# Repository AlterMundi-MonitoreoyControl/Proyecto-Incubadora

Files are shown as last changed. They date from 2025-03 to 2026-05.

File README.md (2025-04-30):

# LibreIncu 

Is an innovative project aimed at enhancing the efficiency and productivity of poultry incubators in family farming. Developed by Asociación Civil AlterMundi and CTO, this system integrates advanced monitoring and control technologies to optimize temperature and humidity levels, reducing manual labor and increasing hatch rates. Utilizing free hardware and software, the project promotes sustainable agricultural practices and empowers local communities with technical skills. Join us in revolutionizing family farming with technology!

(https://editor.plantuml.com/uml/ZLF1JW8n4BttAoPSXCCUG43mO20a6WvUnCIB2HdQMMtijfks2_ht3Wj85z2OR3RPwNipxxtEJa947wl2YF2XROaU2r2KOsNYCtt6gT5ljY0RGVABl13MAOBMtCfgXSfvXF5mq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)

Each incubator broadcasts a Wi-Fi network with a name that starts with “incu-” followed by a number. A user who wants to control their incubator can connect to this Wi-Fi network and change the incubator paramteres using the android app. Additionally, each incubator also connects to an external Wi-Fi network to send data over the internet to a remote Grafana server.

## LibreIncu en los medios
Aquí encontrarás enlaces a 

### Notas y artículos periodísticos 
Tiempo Argentino.Tiempo Rural.

Crean “LibreIncu”, una incubadora para familias productoras que funciona con software libre
https://bit.ly/LibreIncu

Pagina 12.

Problemas en la salud, maltrato animal y pérdida de soberanía. ¿Qué hacer con la industria avícola?
https://www.pagina12.com.ar/798691-que-hacer-con-la-industria-avicola

Multimedio Comechingones: 

INCUBADORAS LIBRES Y LA SOBERANÍA ALIMENTARIA Y TECNOLÓGICA.
https://www.youtube.com/watch?v=XAIEJV1IsmM

Radio Pueblo 103.3

Somos Tierra (programa) 07/03
“LibreIncu”, una incubadora para familias productoras que funciona con software libre.
https://www.facebook.com/100064102022746/posts/pfbid0N8CtLHdo2AVj12pVsAtcoeShCmByB2GCyXqmLqw75aoo8GYHFhkMTCCCVQQF8PBvl/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

CDM Noticias: 

👉🏽En una entrevista radial con CDM Noticias, Fabricio Puzio, integrante de la organización rural CTO y uno de los impulsores del proyecto, brindó detalles del proyecto
https://cdmnoticias.com.ar/2025/03/11/libreincu-una-incubadora-de-pollos-con-software-libre-para-la-agricultura-familiar-en-cordoba/

### Videos

En este video encontrarán las voces de las comunidades que recibieron la incubadora en 1ra persona:
Youtube: https://youtu.be/KnWVigydmrw
Drive (para descarga archivo):
https://drive.google.com/file/d/1XJGJvUBiZXpjTJCaMYPYS3Le8TjS4YHT/view?usp=drive_link

Este video resume la actividad de febrero de 2025, dónde se realizó una capacitación técnica sobre el uso de la incubadora y su entrega a las comunidades:
Youtube: https://youtu.be/x1D_cCt7HYg
Drive (archivo):
https://drive.google.com/file/d/1NNPJ5_CfbWtDd18YyunTMB_yW_l8wr9t/view?usp=drive_link

En este video, encontrarán las voces del Equipo de Altermundi, reflexionando sobre el proceso de desarrollo.
Youtube: https://youtu.be/SZky4Ak8hUw
Drive (archivo):
https://drive.google.com/file/d/1BhJ7BwKUeTCceVNzBBIgxEsvleegejvH/view?usp=drive_link

En este video encontrarán testimonios sobre lo que implica el proyecto de desarrollo para las organizaciones involucradas.
Youtube: https://youtu.be/OzdKqgwdBYY

En este video encontrarán una presentación técnica Incubadora, con sus componentes:
https://www.youtube.com/watch?v=WrC1Y-ACtMo
Corte cuadrado 1:
https://drive.google.com/file/d/1Y_UQ-bno3-HFeVKtA_xg6CsesUtA-4hE/view?usp=drive_link
Corte cuadrado 2:
https://drive.google.com/file/d/13rHx7xk9e1rThg5PIM3QHikm3YS5sNPg/view?usp=drive_link

En este video encontrarán testimonios sobre la 1er Capacitación realizada con las comunidades sobre manejo productivo de huevos fértiles e incubadora.
https://youtu.be/IfGGvOIJ1b8
https://drive.google.com/file/d/1ajWQofPJQxNfXo5LtOdFrOzkCoTbWGiC/view?usp=sharing

## made with :heart: by:

<p align="center" width="100%">
    
</p>

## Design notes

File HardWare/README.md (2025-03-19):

# Project-Incubadora Hardware



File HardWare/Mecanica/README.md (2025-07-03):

# LibreIncu: 3D Model Overview

This repository includes a 3D printable part of the LibreIncu incubator project.

## 🔍 STL Preview

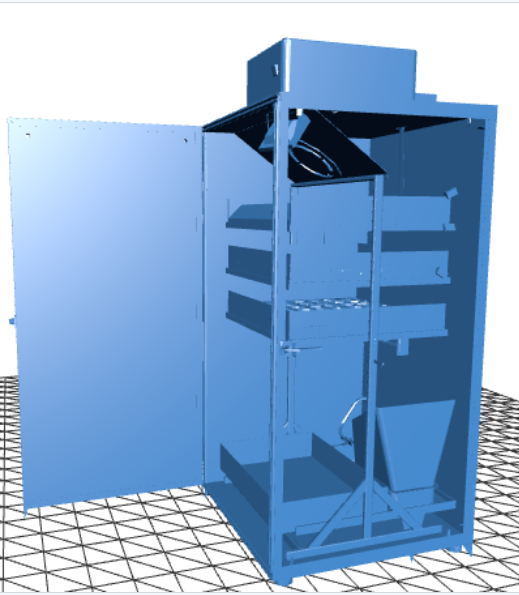
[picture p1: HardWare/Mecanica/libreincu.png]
LibreIncu 3D Preview


## 📦 Download STL

You can download the 3D model file here:

🔗 [`LibreIncu-STL.simple.stl`](./LibreIncu-STL.simple.stl)

## 🛠️ About the Model

- Format: STL (for 3D printing)
- Material suggestion: PLA or PETG
- Print orientation: Flat on base
- License: [Your License Here]

## 📁 File Location

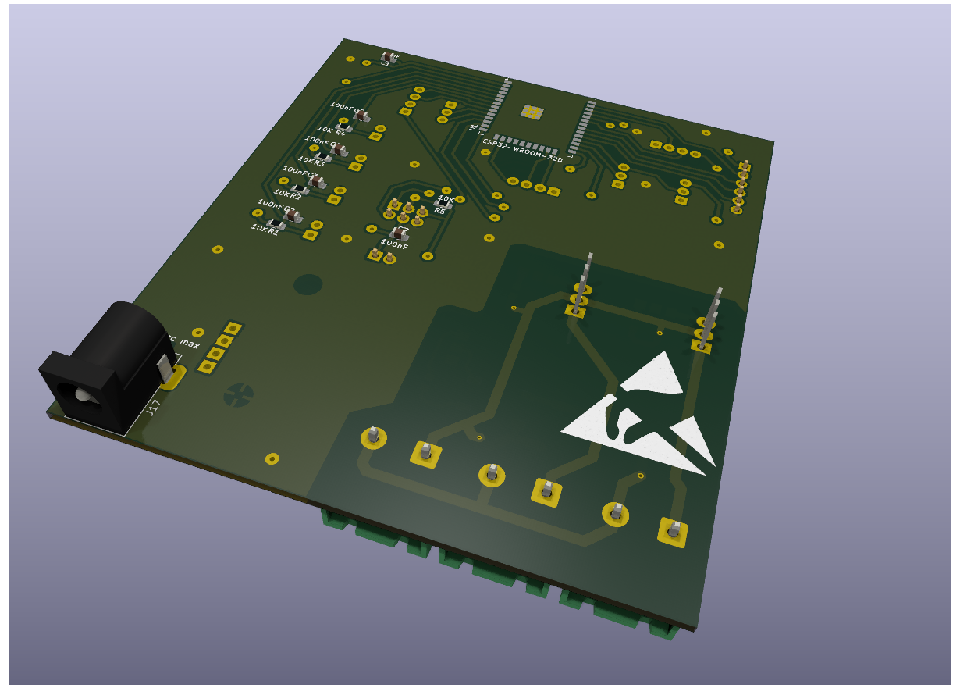
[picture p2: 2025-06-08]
HardWare/Electro/Olivia_control/v0.2/v0.2-vista2.png

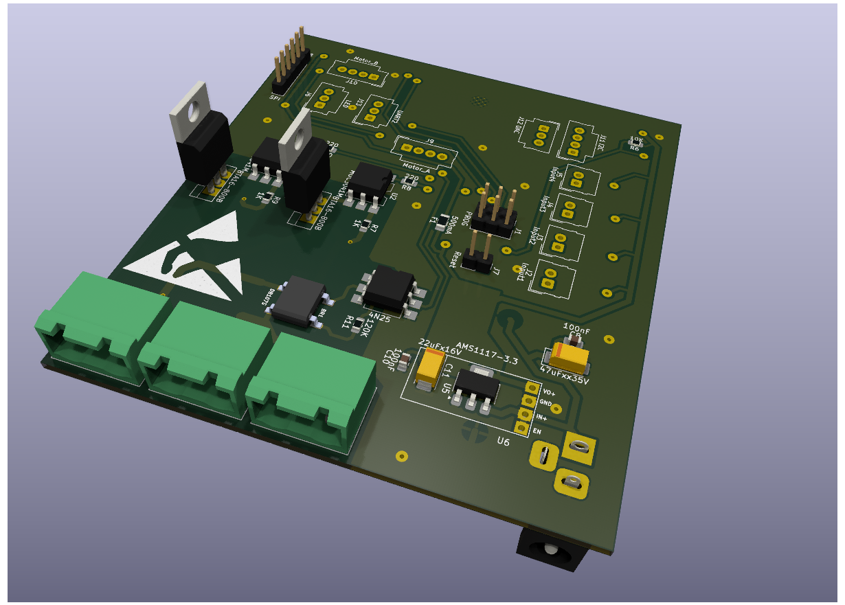
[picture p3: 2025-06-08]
HardWare/Electro/Olivia_control/v0.2/v0.2-vista1.png

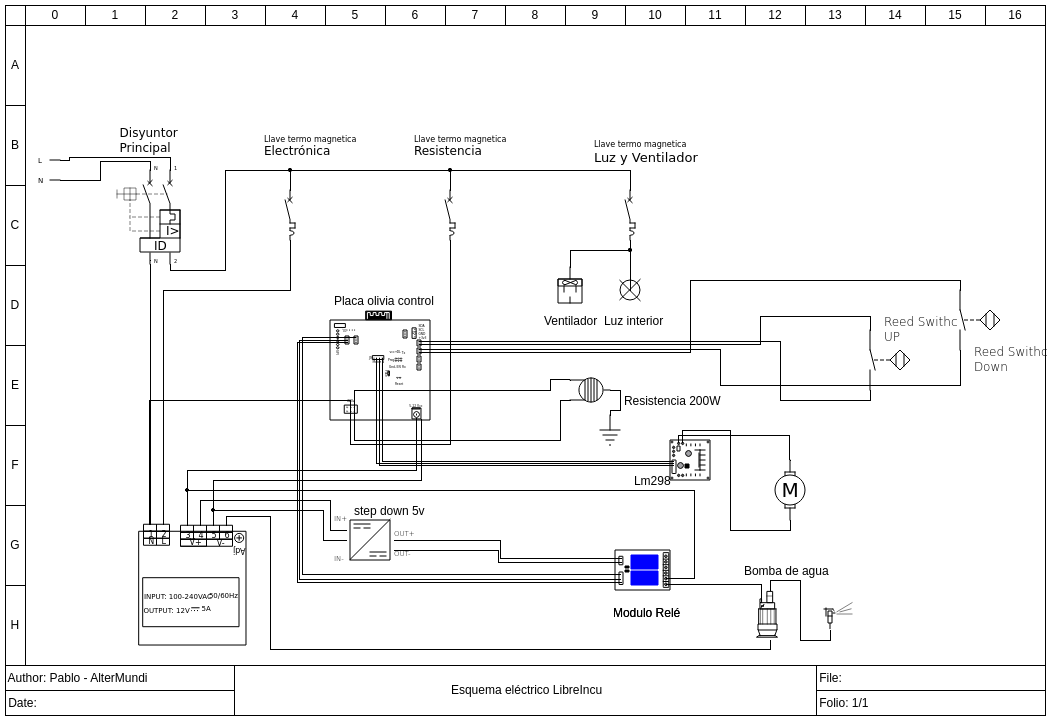
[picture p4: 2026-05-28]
HardWare/Electro/1_esquema_eléctrico_libreincu.png

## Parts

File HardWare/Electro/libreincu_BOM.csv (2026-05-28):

Subsistema | Componente | Cantidad | Especificación | Estado | Referencia / Link | Notas | Responsable
Alimentación | Fuente switching | 1 | 12V 5A con ventilación FSI-1205-Classic | definido | https://www.mercadolibre.com.ar/fuente-switching-12v-5a-proteccion-ventilada-fsi-1205-clasic/p/MLA308325457
Alimentación | Módulo step down | 1 | LM2596 regulable 1,3V–35V 3A | definido | https://articulo.mercadolibre.com.ar/MLA-1249465246-modulo-regulador-fuente-step-down-lm2596s-130v-35v-pack-x10-_JM |  | Fabri
Alimentación | Gabinete plástico | 1 | 25x25 o 20x20 cm IP65 | definido | https://www.mercadolibre.com.ar/caja-estanca-plastica-210x310x110-mm-blanca-ip65-color-blanco/p/MLA268881998
Alimentación | Disyuntor diferencial | 1 | Bipolar 2x 25A | definido | https://articulo.mercadolibre.com.ar/MLA-1548430354-interruptor-diferencial-disyuntor-bipolar-2x-25a-baw-_JM
Control electrónico | PCB (placa de control Olivia) | 1 | Diseño propio LibreIncu | repositorio | https://github.com/AlterMundi-MonitoreoyControl/Proyecto-Incubadora | Ver diseño en repositorio GitHub
Control electrónico | Sensor BME280 | 1 | Temperatura / humedad / presión I²C | verificar |  | Hay de impresora — averiguar si sirven. 3 dudosos | Pablo
Control electrónico | Sensores Reed (finales de carrera) | 2 | Sensor magnético para puerta/ventana | definido | https://articulo.mercadolibre.com.ar/MLA-878544727-sensor-magnetico-para-alarma-puerta-y-ventana-seguridad-_JM | Pack x6
Control electrónico | Resistencia calefactora | 1 | 200W (tipo panchera industrial) | definido | https://myaccount.mercadolibre.com.ar/my_purchases/200000938165593 |  | Fabri
Electricidad y protecciones | Interruptor termomagnético | 3 | Automático miniatura DIN límite 782105 | definido | https://articulo.mercadolibre.com.ar/MLA-908151554-interruptor-automatico-miniatura-para-riel-din-sica-limit-782105
Electricidad y protecciones | Llave palanca (interruptor) | 2 | 250V on-off 2 contactos | definido | https://articulo.mercadolibre.com.ar/MLA-908151554-llave-palanca-10a-250v-on-off-2-contactos-interruptora-_JM
Electricidad y protecciones | Cable taller tripolar | 2 | 3x2 5 mm² | 5 mm² | definido | https://articulo.mercadolibre.com.ar/MLA-912939764-cable-taller-tripolar-3-x-25-mm-x-mts-_JM | Metros según diseño
Electricidad y protecciones | Cable para sensores | 3 | Multiconductor fino | definido |  | Hay de impresora | Pablo
Electricidad y protecciones | Prensacables | 5 |  | definido
Electricidad y protecciones | Enchufe | 1 | Ficha macho recto salida trasera 10A | definido | https://articulo.mercadolibre.com.ar/MLA-1404782284-pack-x10-ficha-macho-richi-salida-trasera-3-patas_JM
Electricidad y protecciones | Luz LED | 1 | Proyector reflector LED 10W luz fría | definido | https://articulo.mercadolibre.com.ar/MLA-1400729612-proyector-reflector-led-10w-luz-fria-blanco_JM
Electricidad y protecciones | Resistencia horno (grill) | 1 | 36A 53cm — horno eléctrico grill velas | definido | https://articulo.mercadolibre.com.ar/MLA-654604457-resistencia-horno-electrico-grill-velas_JM
Electricidad y protecciones | Cable bipolar 0 | 5mm |  | 24AWG rojo-negro LED x10m | definido | https://articulo.mercadolibre.com.ar/MLA-877971472-cable-bipolar-de-05mm-24-awg-rojo-y-negro-tira-led-x10m-_JM
Humidificación y mecánica | Bomba de agua | 1 | Singflo/SEAFLO 12VCC 4,3 LPM 35 PSI — diafragma con presostato integrado. 3,5A. Salida 3/8". | definido | https://www.mercadolibre.com.ar/bomba-de-agua-43-lpm-12-v-motorhome-casa-rodante-adrogue/up/MLAU276483609
Humidificación y mecánica | Motorreductor volteo | 1 | Ignis MR08B-012004 — 12 VCC 4W cupla máx. 88 kgf·cm eje 8mm 17 rpm | definido | https://ignismotor.com/STD-ES/PDF/MR08B-012004.pdf | Volteo automático de bandejas
Humidificación y mecánica | Ventilador turbina con rodamiento | 1 | 220 VAC 50Hz — 120x120mm axial con rulemán. Modelo tipo CT4 A7 o similar. | definido | https://articulo.mercadolibre.com.ar/MLA-620399442-turbina-cooler-fan-extractor-220v-ruleman-4-pulgadas-120x38m-_JM | Circulación forzada de aire interior. VT-POWER CT4 o equivalente con rodamiento (no manguito)
Humidificación y mecánica | Caja estanca 20x25 | 1 | 210x310x110mm IP65 | definido | https://www.mercadolibre.com.ar/caja-estanca-plastica-210x310x110-mm-blanca-ip65-color-blanco/p/MLA268881998

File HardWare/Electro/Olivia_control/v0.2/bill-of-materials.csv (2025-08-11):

Reference | Value | Footprint | Qty
BR1 | DB107S | lib:DIOB_DB107S | 1
C1 | 10uF | Capacitor_SMD:C_0805_2012Metric_Pad1.18x1.45mm_HandSolder | 1
C2,C3,C4,C5,C7,C8,C10 | 100nF | Capacitor_SMD:C_0805_2012Metric_Pad1.18x1.45mm_HandSolder | 7
C9 | 47uFxx35V | Capacitor_Tantalum_SMD:CP_EIA-6032-28_Kemet-C_Pad2.25x2.35mm_HandSolder | 1
C11 | 22uFx16V | Capacitor_Tantalum_SMD:CP_EIA-6032-28_Kemet-C_Pad2.25x2.35mm_HandSolder | 1
F1 | 500mA | Fuse:Fuse_1206_3216Metric_Pad1.42x1.75mm_HandSolder | 1
J1 | PROG | Connector_PinHeader_2.54mm:PinHeader_2x03_P2.54mm_Vertical | 1
J2 | Input1 | Connector_Molex:Molex_SL_171971-0002_1x02_P2.54mm_Vertical | 1
J3 | Input2 | Connector_Molex:Molex_SL_171971-0002_1x02_P2.54mm_Vertical | 1
J4 | Input3 | Connector_Molex:Molex_SL_171971-0002_1x02_P2.54mm_Vertical | 1
J5 | Input4 | Connector_Molex:Molex_SL_171971-0002_1x02_P2.54mm_Vertical | 1
J6 | LED | Connector_Molex:Molex_SL_171971-0003_1x03_P2.54mm_Vertical | 1
J7 | Reset | Connector_PinHeader_2.54mm:PinHeader_1x02_P2.54mm_Vertical | 1
J8 | SPI | Connector_PinHeader_2.54mm:PinHeader_1x06_P2.54mm_Vertical | 1
J9 | Motor_A | Connector_Molex:Molex_SL_171971-0004_1x04_P2.54mm_Vertical | 1
J10 | Motor_B | Connector_Molex:Molex_SL_171971-0004_1x04_P2.54mm_Vertical | 1
J11 | I2C | Connector_Molex:Molex_SL_171971-0004_1x04_P2.54mm_Vertical | 1
J12 | DAC | Connector_Molex:Molex_SL_171971-0003_1x03_P2.54mm_Vertical | 1
J13 | UART2 | Connector_Molex:Molex_SL_171971-0003_1x03_P2.54mm_Vertical | 1
J14 | TRIAC OUT_A | Connector_Phoenix_GMSTB:PhoenixContact_GMSTBA_2,5_2-G-7,62_1x02_P7.62mm_Horizontal | 1
J15 | TRIAC OUT_B | Connector_Phoenix_GMSTB:PhoenixContact_GMSTBA_2,5_2-G-7,62_1x02_P7.62mm_Horizontal | 1
J16 | 220V IN | Connector_Phoenix_GMSTB:PhoenixContact_GMSTBA_2,5_2-G-7,62_1x02_P7.62mm_Horizontal | 1
J17 | In12V | Connector_BarrelJack:BarrelJack_Horizontal | 1
Q1,Q2 | BTA16-800B | Package_TO_SOT_THT:TO-220-3_Vertical | 2
R1,R2,R3,R4,R5,R6 | 10K | Resistor_SMD:R_0805_2012Metric_Pad1.20x1.40mm_HandSolder | 6
R7,R9 | 1K | Resistor_SMD:R_0805_2012Metric_Pad1.20x1.40mm_HandSolder | 2
R8,R10 | 220 | Resistor_SMD:R_0805_2012Metric_Pad1.20x1.40mm_HandSolder | 2
R11 | 120K | Resistor_SMD:R_0805_2012Metric_Pad1.20x1.40mm_HandSolder | 1
U1 | ESP32-WROOM-32D | RF_Module:ESP32-WROOM-32D | 1
U2,U3 | MOC3041M | Package_DIP:SMDIP-6_W9.53mm | 2
U4 | 4N25 | Package_DIP:SMDIP-6_W9.53mm | 1
U6 | HW-613 | Connector_PinHeader_2.54mm:PinHeader_1x04_P2.54mm_Vertical | 1

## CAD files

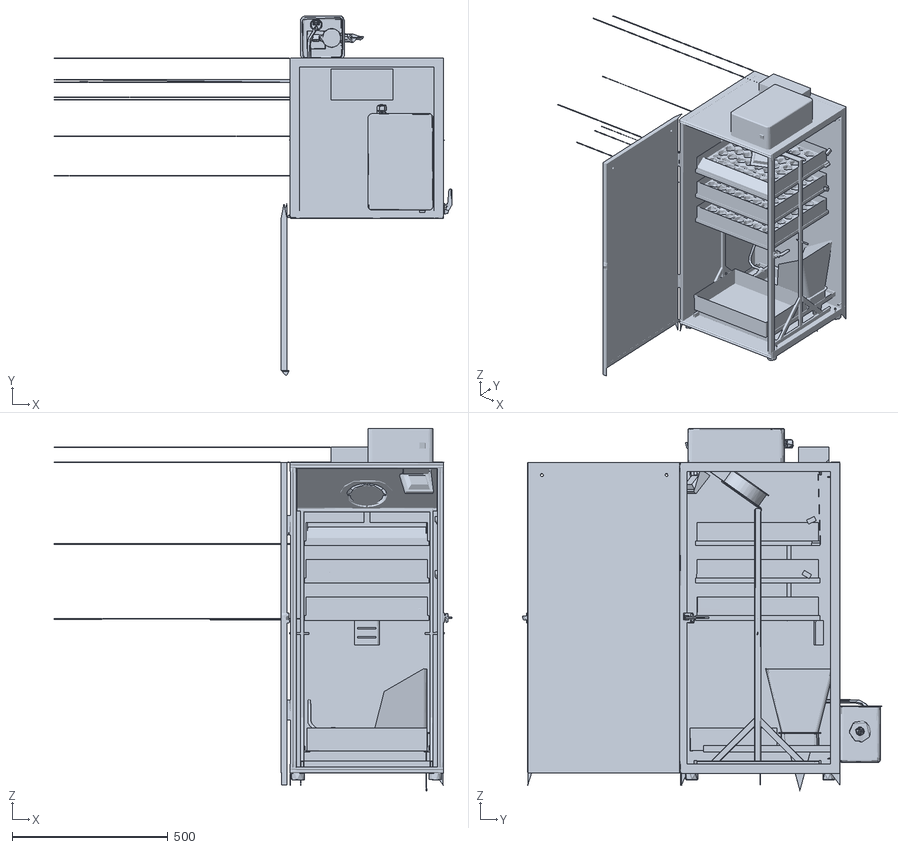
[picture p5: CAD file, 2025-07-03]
HardWare/Mecanica/LibreIncu-STL.simple.stl
1277.2 x 1154.4 x 1162.8

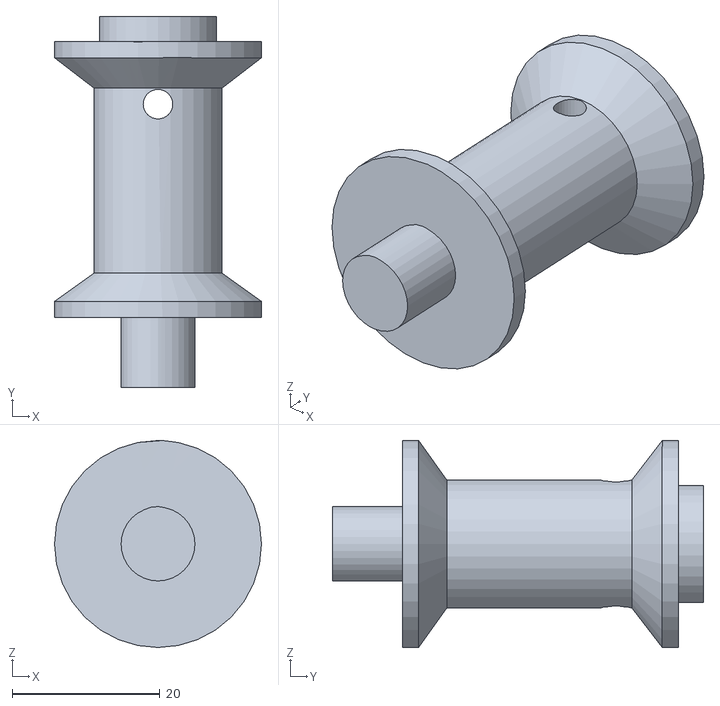
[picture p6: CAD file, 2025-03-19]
HardWare/Mecanica/STLs_rotacion/Polea.stl
28.1 x 50.3 x 28.1

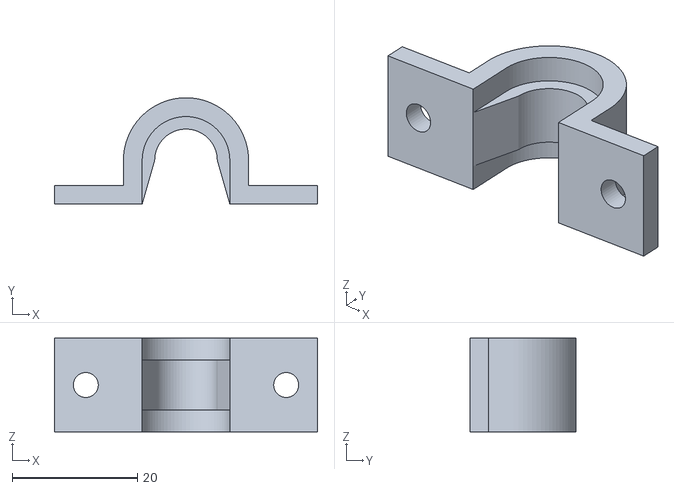
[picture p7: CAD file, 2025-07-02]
HardWare/Mecanica/ALT-INC001-12-03.STL
42.0 x 17.0 x 15.0

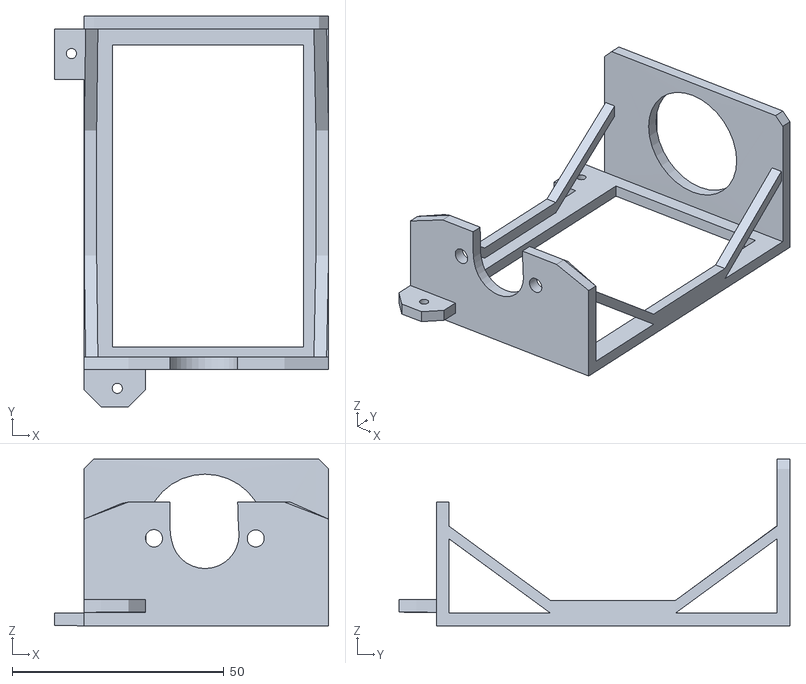
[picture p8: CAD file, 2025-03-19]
HardWare/Mecanica/STLs_rotacion/SoporteMotor.stl
64.8 x 92.4 x 39.4

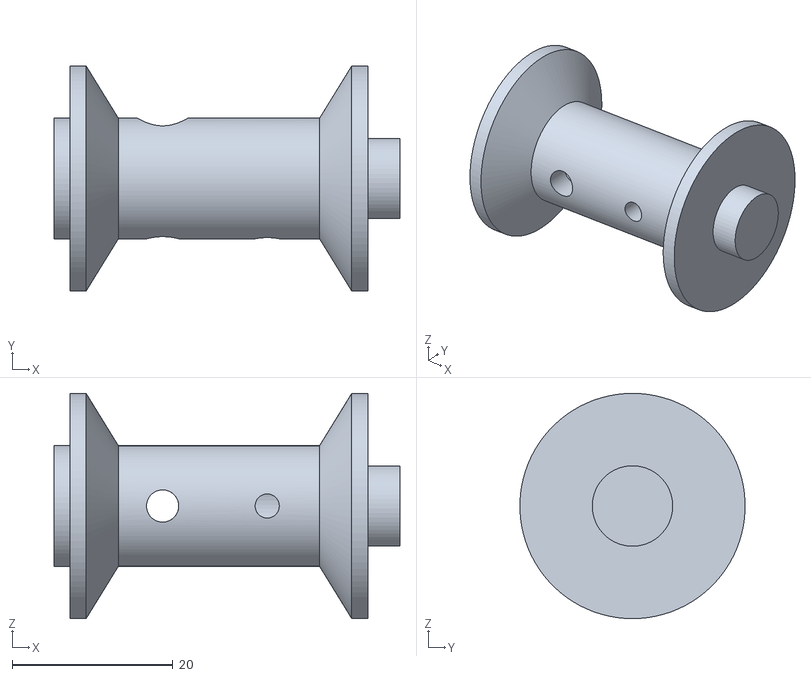
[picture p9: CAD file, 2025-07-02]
HardWare/Mecanica/ALT-INC001-05-01.STL
43.0 x 28.0 x 28.0

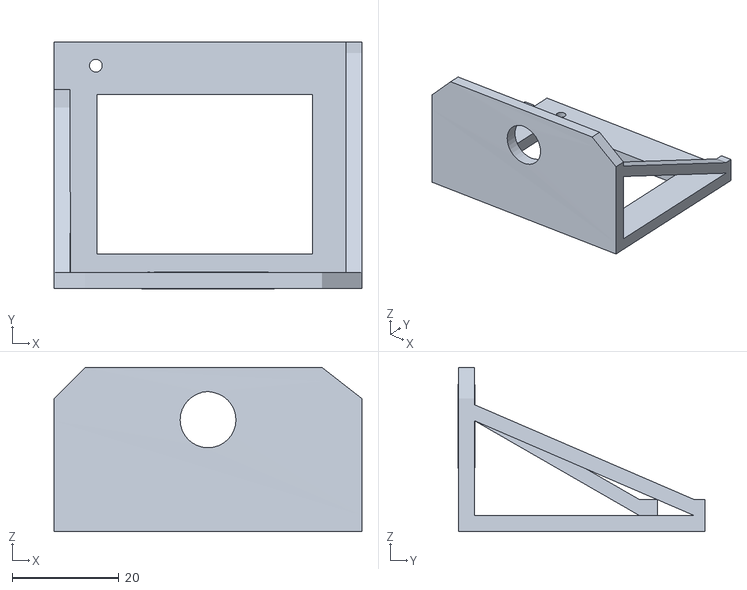
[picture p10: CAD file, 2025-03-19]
HardWare/Mecanica/STLs_rotacion/SoportePolea.stl
57.8 x 46.3 x 30.8

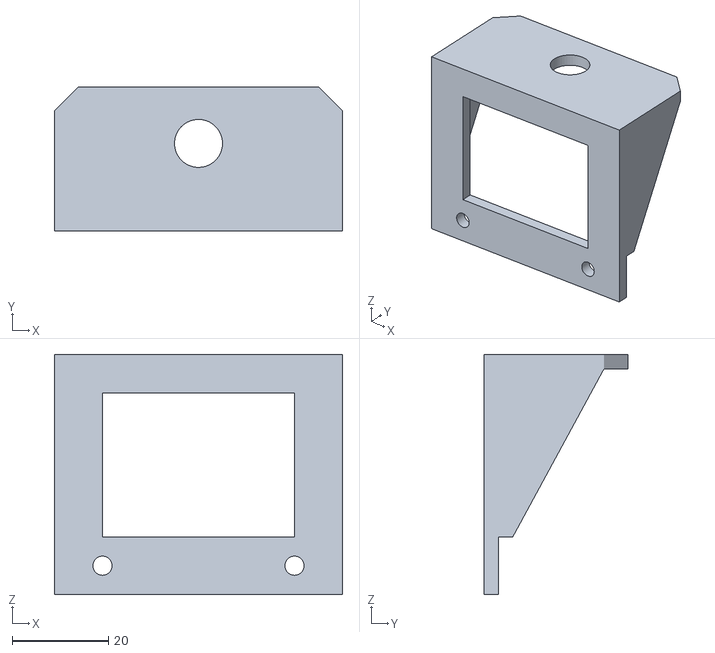
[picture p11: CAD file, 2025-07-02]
HardWare/Mecanica/ALT-INC001-05-02.STL
60.0 x 30.0 x 50.0

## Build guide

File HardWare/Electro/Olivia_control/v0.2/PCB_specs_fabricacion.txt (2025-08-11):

Resumen de Especificaciones para el Pedido
Layers: 2
Material: FR-4
Dimensions: 90x100mm
PCB Thickness: 1.6mm
Copper Weight: 1 oz
Min. Trace/Spacing: 10/10 mil
Min. Hole Size: 0.2mm
Solder Mask: Purple
Silkscreen: White
Surface Finish: HASL (Lead-Free)
Quantity: [La cantidad de prototipos que necesites]

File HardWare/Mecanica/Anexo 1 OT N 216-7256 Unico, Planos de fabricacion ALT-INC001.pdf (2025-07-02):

Informe de Asistencia Técnica | OT N° 216-7256 Único Anexo 1 Página 1 de 2

Denominación de referencia:
Asistencia técnica en el rediseño de incubadora de huevos “LibreIncu - 150” desarrollada por el solicitante -Etapa 1: Relevamiento del prototipo y generación de documentación técnica de fabricación.

Planos de fabricación ALT-INC001
La tabla a continuación contiene el índice de los planos de conjunto y de detalle que se encuentran embebidos en formato “.pdf” en este anexo:
Plano N° | Archivo formato .pdf embebido | Descripción | Form.
1 | ALT-INC001-AP | Árbol de planos | A4
2 | ALT-INC001-00 | Conjunto general | A2
3 | ALT-INC001-01-00 | Conjunto cuerpo | A3
4 | ALT-INC001-01-01 | - Placa superior | A4
5 | ALT-INC001-01-02 | - Placa lateral | A4
6 | ALT-INC001-01-03 | - Placa inferior | A4
7 | ALT-INC001-01-04 | - Placa fondo | A4
8 | ALT-INC001-01-05 | - Perfil U | A4
9 | ALT-INC001-01-06 | - Perfil L | A4
10 | ALT-INC001-02-00 | Conjunto estructura interna | A2
11 | ALT-INC001-02-01 | - Estructura | A3
12 | ALT-INC001-02-02 | - Soporte inferior | A4
13 | ALT-INC001-02-03 | - Chapa inferior | A4
14 | ALT-INC001-02-04 | - Porta bandeja superior | A4
15 | ALT-INC001-02-05 | - Porta bandeja media | A4
16 | ALT-INC001-02-06 | - Porta bandeja inferior | A4
17 | ALT-INC001-02-07 | - Barra de movimiento | A4
18 | ALT-INC001-03-00 | Conjunto puerta | A4
19 | ALT-INC001-03-01 | - Placa puerta | A4
20 | ALT-INC001-03-02 | - Perfil U | A4
21 | ALT-INC001-04-00 | Conjunto depósito agua | A4
22 | ALT-INC001-04-01 | - Depósito agua | A4
23 | ALT-INC001-05-00 | Conjunto motor | A4
24 | ALT-INC001-05-01 | - Polea correa | A4
25 | ALT-INC001-05-02 | - Soporte polea | A4
26 | ALT-INC001-06 | Deflector ventilador | A4
27 | ALT-INC001-07 | Cubre motor | A3
28 | ALT-INC001-08 | Tablero eléctrico | A3
29 | ALT-INC001-09-00 | Conjunto bandeja 50 huevos | A3

Informe de Asistencia Técnica | OT N° 216-7256 Único Anexo 1 Página 2 de 2
30 | ALT-INC001-09-01 | - Chapa bandeja | A3
31 | ALT-INC001-09-02 | - Malla | A4
32 | ALT-INC001-09-03 | - Cortes maple plástico | A3
33 | ALT-INC001-10-00 | Conjunto bandeja 58 huevos | A3
34 | ALT-INC001-10-01 | - Chapa bandeja | A3
35 | ALT-INC001-11-00 | Conjunto bandeja piso | A3
36 | ALT-INC001-11-01 | - Chapa lateral | A3
37 | ALT-INC001-11-02 | - Chapa fondo | A4
38 | ALT-INC001-12-00 | Conjunto humidificador | A3
39 | ALT-INC001-12-01 | - Soporte resistencia | A4
40 | ALT-INC001-12-02 | - Chapa impacto agua | A3
41 | ALT-INC001-12-03 | - Soporte pico spray | A4

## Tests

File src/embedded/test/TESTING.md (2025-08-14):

# Testing guide

LibrePollo has unit tests that help us add new features while keeping maintenance effort contained.

We encourage contributors to write [tests](https://en.wikipedia.org/wiki/Unit_testing)  when adding new functionality and also while fixing [regressions](https://en.wikipedia.org/wiki/Regression_testing).

LibreMesh unit testing is based in the powerful [busted](https://lunarmodules.github.io/busted/) library which has a very good documentation.

## Install required software
```
apt-get install luarocks
sudo luarocks install --server=https://luarocks.org/dev ltn12
sudo luarocks install luasockets
sudo luarocks install busted
sudo luarocks install json-lua 
sudo luarocks install inspect
```
## How to run the tests

Just execute `busted test_*` inside test folder.

## Testing directory structure

Test files for source module `foo.lua` live inside a `test` directory with its names begining with `test_`:

```
test/test_foo.lua

```

Testing utilities, fake libraries and integration tests live inside a root `test/` directory:

```
tests/test_some_integration_tests.lua
tests/test_other_general_tests.lua
tests/fake/bazlib.lua
tests/tests/test_bazlib.lua
```

## How to write tests

Here is a very simple test of a library `foo`:
```[lua]
local foo = require 'foo'

describe('foo library tests', function()
    it('very simple test of f_sum(a, b)', function()
        assert.is.equal(4, foo.f_sum(2, 2))
        assert.is.equal(2, foo.f_sum(2, 0))
        assert.is.equal(0, foo.f_sum(2, -2))
    end)
end)
```
## manual testing
```lua
dofile('credentials.lua')

gpio.config({ gpio = { GPIOREEDS_DOWN, GPIOREEDS_UP }, dir = gpio.IN, pull = gpio.PULL_UP })

```
TODO: Implement as a post-power-on self-test or in a app command

### Test Rotation


We are using motor A inputs. So the first thing to test is the digital inputs.
Leave  a jumper in EN_A like the picture and remove the jumper from EN_B.
Use the other pin from EN_B witch should be in a logical 1 state to activate "in 1" first and then "in 2". Just conect a Female to Female wire betwen the pins and watch the engine rotate in both directions. 



Move down:
```lua
-- turn on
gpio.write(GPIOVOLTEO_EN,1)
gpio.write(GPIOVOLTEO_UP,0)
gpio.write(GPIOVOLTEO_DOWN,1)
-- turn off
gpio.write(GPIOVOLTEO_DOWN,0)
```

Move up:
```lua
gpio.write(GPIOVOLTEO_EN,1)
gpio.write(GPIOVOLTEO_DOWN,0)
gpio.write(GPIOVOLTEO_UP,1)
-- turn off
gpio.write(GPIOVOLTEO_UP,0)
```

### Test Sensors
Sensors are conected to cpu inputs, inputs are maped to gpio 34 35 36 and 39
```lua
gpio.config({ gpio = { 34, 35,36,39 }, dir = gpio.IN, pull = gpio.PULL_UP })
print(gpio.read(34),gpio.read(35),gpio.read(36),gpio.read(39))
```
usually GPIOREEDS_UP and GPIOREEDS_DOWN are 34 and 39
```lua
print(gpio.read(GPIOREEDS_UP), gpio.read(GPIOREEDS_DOWN))
```

When the sensor is near the magnet, it switches to 0.  
Test both the upper and lower sensors.

### Test Resistor

Turn on:
```lua
gpio.write(GPIORESISTOR,1)
```

Turn off:
```lua
gpio.write(GPIORESISTOR,0)
```

### Test Humidifier

Turn on:
```lua
gpio.write(GPIOHUMID,0)
```

Turn off:
```lua
gpio.write(GPIOHUMID,1)
```

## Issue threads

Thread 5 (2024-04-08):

Mejorar Humedad en prototipo 1.0

fabriciopetiso, 2024-04-08:
Llevarlo a mas del 60% cambiando la fuentes de agua

Pablomonte, 2024-04-17:
Sin fuente de humedad la incubadora se mantuvo funcionando cerca del 27% de humedad.
Al incorporar 2 humidificadores se alcanzó un 37% de humedad.
La experiencia pendiente consiste en agregar otro humidificador y estimar si el incremento de humedad sería lineal o hay otras variables. Además de estudiar el comportamiento y robustez de los elementos humidificadores en tanto funcionen 24/7

fabriciopetiso, 2024-05-21:
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

Estamos  cerca, se puede agrandar la bandeja unos 5 cm de lado, y bastante de profundidad.

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

Pablomonte, 2024-10-24:
el prototipo 1.0 fué
;)

Closed 2024-10-24.

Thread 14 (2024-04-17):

Planificación final para la fabricación

fabriciopetiso, 2024-04-17:
Hacer un paso a paso detallado de cada parte y componente, listado de materiales y check list de herramientas para cada módulo de la incubadora. Ver quiénes y donde se haría.

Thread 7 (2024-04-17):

Validar definitivamente medidas incubadora y maples para la nueva etapa

fabriciopetiso, 2024-04-17:
Asegurarnos que la capacidad este cerca de los 150 huevos. Sino no tiene sentido económico la inversión.

Pablomonte, 2024-04-17:
Teniendo en cuenta las medidas de los maples standard 30 x 30cm para 30 huevos, en 35 x 35 cm podríamos colocar 49 huevos por bandeja.
Con las medidas actuales de la incu  podrían confeccionarse bandejas portahuevos de hasta 36,5 x 36,5 cm

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

fabriciopetiso, 2024-04-18:
Cuando hagamos el montaje de 24 v el 2/5, podemos evaluar si se puede achicar la carcasa de altura.

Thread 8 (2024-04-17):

Reemplazar las resistencias y ventiladores por otros componentes de menor demanda energética.

fabriciopetiso, 2024-04-17:
En base a lo propuesto por Río IV

Pablomonte, 2024-10-24:
Reemplazamos las resistencias de 2 ohms de continua por una resistencia calefactor para incubadora de 200W 220v.
Hasta ahora los resultados son aceptables, no genera "tostados" en las paredes ni piso de la incu y alcanza sin problemas la temperatura de régimen.

Closed 2024-10-24.

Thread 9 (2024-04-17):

Reemplazar la bandeja de agua por un humidificador

fabriciopetiso, 2024-04-17:
Validar en un cruce con río IV

Ojo, acá hace falta desarrollo de soft

Pablomonte, 2024-04-17:
también implica agregar un inductor en la placa de control para exitar la membrana del humidificador

Pablomonte, 2024-10-24:
Reemplazamos el humidificador de membrana por un microaspersor alimentado por una bomba de nafta genérica y un sistema de provisión permanente de agua.

Closed 2024-10-24.

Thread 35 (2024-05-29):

Crear un plan de pruebas manuales

Santiagocetran, 2024-05-29:
Crear un plan de pruebas para verificar antes de confirmar el cambio de los archivos.
Un documento con una "checklist" donde se vea todo lo que debe estar funcionando para aprobar un pull request. Para que lo que estamos aprobando no rompa otras cosas.

Por un lado tenemos las pruebas unitarias, y por otro lado tenemos pruebas manuales para confirmar que todo siga funcionando correctamente

javierbrk, 2024-11-28:
https://github.com/AlterMundi-MonitoreoyControl/Proyecto-Incubadora/blob/main/src/embedded/test/TESTING.md

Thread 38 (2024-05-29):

OTA y fall back

Santiagocetran, 2024-05-29:
Pensar en implementar OTA updates (over the air updates)

links que vio jere con gio:
https://www.instructables.com/ESP8266-OTA-LUA-With-WEB-UI-MANAGEMENT-Nodemcu-Fir/
https://unifiedpush.org/

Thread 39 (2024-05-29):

Por elmomento servir estaticamente todo el filesystem desde el web browser

Santiagocetran, 2024-05-29:
agregar un get para obtener json y otro para csv tipo estatico que muestre capturas de datos y el json de configuracion.

`httpd.static("config.json", "application/json")`

httpd_uri: httpd_register_uri_handler: handler config.json with method 1 already registered
Intente de esta forma pero me dice que ya tengo un metodo registrado, pero es la unica ruta estatica 😿

javierbrk, 2024-08-05:
httpd.static("*.json", "text/csv") -- Serve CSV files under web/

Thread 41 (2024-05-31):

not enough memory

Santiagocetran, 2024-05-31:
```lua
local mem_used, _, _ = collectgarbage("count")
print("memoria en uso: " .. mem_used)
-- Forzar una recoleccion de memoria
collectgarbage("collect")
--
local actual_mem = node.heap()
print("Memoria actual: " .. actual_mem )
```
https://gist.github.com/TerryE/eb630669a088e860193d1a10ab3686f5

https://github.com/nodemcu/nodemcu-firmware/issues/457

javierbrk, 2024-08-05:
asociado con #72

Closed 2024-09-03.

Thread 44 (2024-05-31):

back log alertas

Santiagocetran, 2024-05-31:
- [ ]  crear la view
- [ ] asociar el ntfy con el hash para mostrar el historial de notificaciones
- [ ] buscar la forma de que la campanita sea roja cuando hay notificaciones sin ver
- [ ] checkear trello y https://f-droid.org/es/2022/12/18/unifiedpush.html

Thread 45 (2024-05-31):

back log alertas

Santiagocetran, 2024-05-31:
- [ ]  crear la view
- [ ] asociar el ntfy con el hash para mostrar el historial de notificaciones
- [ ] buscar la forma de que la campanita sea roja cuando hay notificaciones sin ver
- [ ] checkear trello y https://f-droid.org/es/2022/12/18/unifiedpush.html

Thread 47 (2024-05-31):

web view frontend

Santiagocetran, 2024-05-31:
- [x]  modificar la vista para que muestre un web view de grafana
- [x]  ver solo un panel de grafana

javierbrk, 2024-08-05:
Necesitamos habilitar una instancia de grafana de monitoreo y control

Closed 2024-08-05.

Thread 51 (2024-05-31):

contador view - front end

Santiagocetran, 2024-05-31:
- [ ]  hacer un boton para cada bandeja
- [ ]  los botones deben ponerse rojos una vez presionados
- [ ] al presionarse para iniciar el contador mostrar un pop up que diga que los huevos deben ser cambiados a nacedora en 18 dias
- [ ]  al presionarse si ya esta en rojo mostrar un pop up que diga "esta por reiniciar el proceso, esta seguro?"
- [ ]  crear evento en calendario? averiguar que onda
- [ ]  cuando el boton se aprieta enviar json de configuracion con el time

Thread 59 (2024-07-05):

implementar control de humedad

javierbrk, 2024-07-05:
Control de humedad similar a control de temperatura
agregar verificacion de tiempo de encendido (ver documentacion de cuanto tiempo debe estar funcionando y cuanto debe estar apagado)

javierbrk, 2024-08-05:
esto esta encaminado pero tiene un bug, sera mejor usar el uptime que la fecha para no ser afectados por el cambio de horario al arrancar.

Closed 2024-09-03.

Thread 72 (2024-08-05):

verificar el tema de la memoria con los envios de logs en grafana

javierbrk, 2024-08-05:
En las pruebas con la incubadora de fabri el sistema explotó porque se quedaba sin memoria cuando mandaba muchos mensajes... verificar si esto sigue siendo asi ...

javierbrk, 2024-08-05:
Probar que esto se repita, intentar  minizar la cantidad de mensajes para ver si eso resuelve el problema .. .

javierbrk, 2024-08-05:
pensar en una estrategia de enviar solo cosas importanes

JereC4str0, 2024-08-13:
estoy depurando esto y encontré algo nuevo :

```[0;31mE (69541) HTTP_CLIENT: Connection failed, sock < 0 [0m
 [0;33mW (69671) http: esp_http_client_perform returned error 28674 [0m
 [0;33mW (69681) http: esp_http_client_perform returned error 28674 [0m
 [0;33mW (69681) http: esp_http_client_perform returned error 28674 [0m
 [0;33mW (69681) http: esp_http_client_perform returned error 28674 [0m
 [0;33mW (69691) http: esp_http_client_perform returned error 28674 [0m
 [0;33mW (69701) http: esp_http_client_perform returned error 28674 [0m
 [0;33mW (69701) http: esp_http_client_perform returned error 28674 [0m
cannot create rtos task
stack traceback:
	[C]: ?
	[C]: in function 'post'
	SendToGrafana.lua:91: in function <SendToGrafana.lua:82>
error de loggg -28674
error de loggg -28674
error de loggg -28674
error de loggg -28674
error de loggg -28674
error de loggg -28674
error de loggg -28674

```

JereC4str0, 2024-08-13:
entiendo que es por falta de memoria, pero antes decia ```out of memory``, cambie el tiempo de envio y sigue haciendo lo mismo

JereC4str0, 2024-08-14:
> pensar en una estrategia de enviar solo cosas importanes

se me ocurre que podríamos guardar los logs en local y despues enviar a grafana lo importante , también podría comparar la memoria que usa para enviar los datos con la que usa para escribir un archivo que se borre cada x cantidad de buffer

Closed 2024-10-28.

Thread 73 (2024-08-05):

Verificar el problema con el uptime y el heap ... reportarlo

javierbrk, 2024-08-05:

javierbrk, 2024-08-05:
verificar que ene le manin se da este problema con el binario nuevo

javierbrk, 2024-08-12:
tenemos un problema de memoria
proponer un cambio donde clasifiques los mensajes en trace, warning, y error y se envien solo los de error sin quedarnos sin memoria

javierbrk, 2024-09-03:
no hay problema

Closed 2024-09-03.

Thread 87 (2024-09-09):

Nuevo campo en endpoint /actual

AnnieScigliano, 2024-09-09:
Agragar un campo llamado "wifi_status" que cambie entre connected y disconnected en base a el estado del wifi.

En la aplicacion connected equivale a contraseña correcta y disconnected a contraseña incorrecta / error de conexión

javierbrk, 2024-10-28:
armar otra pull aparte

Closed 2024-11-05.

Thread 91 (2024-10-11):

Sistem reboots when sensor is broken

javierbrk, 2024-10-11:
Using a bme that is probably broken (wrong vcc gnd connection)
the system simply reboots and only shows the initialization of the credentials... the failure manifests in the start_bme funcion from incubator.lua

Pablomonte, 2024-10-25:
load_values() queda esperando la inicialización del sensor y se reinicia la esp

javierbrk, 2024-10-29:
como se puede simular esta falla ? en el casode que el sensor no este conectado, no hay problema. El problema debe ser en alguna forma específica de conección del sensor. @Pablomonte

javierbrk, 2024-10-29:
se podria depurar el bme280 para ver hasta donde llega poniendo prints en el archivo en la funcion init

Pablomonte, 2024-11-03:
> como se puede simular esta falla ? en el casode que el sensor no este conectado, no hay problema. El problema debe ser en alguna forma específica de conección del sensor. @Pablomonte
Se

Closed 2024-11-03.

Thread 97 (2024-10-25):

Lógica volteo

Pablomonte, 2024-10-25:
Con el imán en el fc "down" luego de intentar movimiento un rato la cinta se desenrosca y vuelve a enroscarse con el sentido invertido.
Ajustar los tiempos para que stop rotation salve las piezas plásticas.
 Pensar si implementar función que cuando mueva el motor y no recive cambios de FC desactive la rotación hasta reiniciar la incu

javierbrk, 2024-10-29:
@Pablomonte cuando puedas montar de nuevo el volteo compartime los tiempos

javierbrk, 2025-02-05:
Ajustar los tiempos para que stop rotation salve las piezas plásticas.

Closed 2025-02-05.

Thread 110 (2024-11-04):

escanear redes visibles por la incubadora  y configurar un wifi nuevo

javierbrk, 2024-11-04:
En algún momento tuvimos un endpoint de scan ... ya no esta.
Esa parte es vital para poder configurara la incubadora.
@JereC4str0  es necesario volver a agregar ese endpoint.
@AnnieScigliano la vista esta disponible y creo que estaba funcionando no ?

JereC4str0, 2024-11-04:
lo sacrificamos juntos, fue cuando no nos quedaban mas endpoints dinamicos

javierbrk, 2024-11-05:
esa funcionalidad es indispensable para que el usuarie pueda conectar la incu !

JereC4str0, 2024-11-10:
#115

Closed 2024-11-12.

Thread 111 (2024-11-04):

cambiar el nombre del wifi del esp

javierbrk, 2024-11-04:
La app deberia conectarse al wifi de la incubadora, el wifi deberia ser de la forma incubadora-nombre.
Donde nombre deberia ser el que cargo el usuario y por defecto la mac del wifi.

JereC4str0, 2024-11-05:
https://nodemcu.readthedocs.io/en/dev-esp32/modules/wifi/#wifistagetmac

JereC4str0, 2024-11-06:
#113

javierbrk, 2024-11-06:
una vez listo el tema del nombre por defecto.
Cada vez que se cambie el nombre de la incubadora debera actualzar las estructuras internas, el archivo de configuracion y el nombre del access point. Eso forzozamente debera reiniciar el AP y desconectar a los usuarios que deberan buscar el nuevo wifi.

JereC4str0, 2024-11-10:
#116

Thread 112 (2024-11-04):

la app deberia conectarse a la ip fija de la incu

javierbrk, 2024-11-04:
Esta issue es solo para asegurarnos de que esto ya es asi.

La persona llega con su teléfono se acerca a la incu, se conecta al wifi incu_nombre. El ip del esp es un ip fijo. Ese deberia ser el que este por defecto en la app para conectarse a la incu.

JereC4str0, 2024-11-04:
la ip fija es 192.168.16.10

Closed 2024-11-12.

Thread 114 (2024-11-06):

Notificaciones

AnnieScigliano, 2024-11-06:
- FW genera un tópico para cada incu (Incubadora-MAC)
- La APP lo levanta desde el config.json
- El tópico es unico para cada incu y varios teléfonos pueden estar asociados al mismo tópico / recibir las mismas notificaciones
- El FW envía las notificaciones (temp, humedad y errores)

- El front maneja: días de incubación
- Si se cae grafana (averiguar)
- cambiar lógica para que el hash no sea modificable en la config view

JereC4str0, 2024-11-07:
ejemplos de push:
https://docs.ntfy.sh/publish/#__tabbed_2_1

JereC4str0, 2024-12-20:
#158

javierbrk, 2025-02-13:
se resolvió con un instructivo de como usar la app de ntfy

Closed 2025-02-13.

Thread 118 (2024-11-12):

incubator wont start if no wifi connection ?? ?

javierbrk, 2024-11-12:
hoy nos conectamos con fabri y me parecio que la incubadora no arrancaba si no se configuraba el wifi correctamente ... @JereC4str0  @Santiagocetran  pueden verificarlo ?
Creen un credentials roto, quiten el config y verifiquen que la incubadora funcione

JereC4str0, 2024-11-12:
Esta comentada la funcion que hace que se reconecte el WiFi en el main [en esta linea](https://github.com/AlterMundi-MonitoreoyControl/Proyecto-Incubadora/blob/0c1dba12f7130e35028b175c824a1ebceb88ce6e/src/embedded/app/wifiinit.lua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)

JereC4str0, 2024-11-14:
encontré la causa de este bug, ahora creo una PR

JereC4str0, 2024-11-14:
# Archivo de credentials enviado roto(comentando el ssid y passwd)

```
 --FileView start
-- This file is only a placeholder.
-- Put your credentials here, and
-- rename the file to remove the underscore.
--SSID = "ChinaNet-POLLO2_0"
--PASSWORD = "1234554321"
TIMEZONE = "UTC+3"

IP_ADDR = ""         -- static IP
NETMASK = ""   -- your subnet
GATEWAY = ""     -- your gateway
--16mb board
GPIOBMESDA = 32
GPIOBMESCL = 33

--inputs
GPIOREEDS_UP = 35
GPIOREEDS_DOWN = 34
--old board
--GPIOBMESDA = 16
--GPIOBMESCL = 0

--outputs
GPIORESISTOR=14
GPIOHUMID = 17

GPIOVOLTEO_UP = 2
GPIOVOLTEO_DOWN = 15
GPIOVOLTEO_EN = 13

INICIALES = "JC"
SERVER="http://grafana.altermundi.net:8086/write?db=cto"

--critical configurations resitor must be turned off
gpio.config( { gpio={GPIORESISTOR}, dir=gpio.OUT })
gpio.set_drive(GPIORESISTOR, gpio.DRIVE_3)
gpio.write(GPIORESISTOR, 0)
-- rotation must be disabled
gpio.config( { gpio={GPIOVOLTEO_EN}, dir=gpio.OUT })
gpio.set_drive(GPIOVOLTEO_EN, gpio.DRIVE_3)
gpio.write(GPIOVOLTEO_EN, 0)
-- humidifier must be turned off
gpio.config( { gpio={GPIOHUMID}, dir=gpio.OUT })
gpio.set_drive(GPIOHUMID, gpio.DRIVE_3)
gpio.write(GPIOHUMID, 1)
--FileView done.
>  [0;32mI (86079) gpio:
```

JereC4str0, 2024-11-14:
## Logs que demuestran que la incubadoira sigue funcionando sin WiFi

```
 [0;32mI (86079) gpio: GPIO[32]| InputEn: 1| OutputEn: 1| OpenDrain: 1| Pullup: 1| Pulldown: 0| Intr:0  [0m
 [0;32mI (86079) gpio: GPIO[33]| InputEn: 1| OutputEn: 1| OpenDrain: 1| Pullup: 1| Pulldown: 0| Intr:0  [0m
 [31m[ERROR 1970-01-01 00:01:25 DST:0] [0m  : Failed to start bme, Please check the cables and connections.
 [0;31mE (86189) esp-tls: couldn't get hostname for :grafana.altermundi.net: getaddrinfo() returns 202, addrinfo=0x0 [0m
 [0;31mE (86189) TRANSPORT_BASE: Failed to open a new connection: 32769 [0m
 [0;31mE (86199) HTTP_CLIENT: Connection failed, sock < 0 [0m
 [0;31mE (86259) esp-tls: couldn't get hostname for :grafana.altermundi.net: getaddrinfo() returns 202, addrinfo=0x0 [0m
 [0;31mE (86259) TRANSPORT_BASE: Failed to open a new connection: 32769 [0m
[!] Failed to start bme, Please check the cables and connections. [0;31mE (86259) HTTP_CLIENT: Connection failed, sock < 0 [0m

 [0;31mE (86339) esp-tls: couldn't get hostname for :grafana.altermundi.net: getaddrinfo() returns 202, addrinfo=0x0 [0m
 [0;31mE (86339) TRANSPORT_BASE: Failed to open a new connection: 32769 [0m
 [0;31mE (86339) HTTP_CLIENT: Connection failed, sock < 0 [0m
 [0;32mI (86349) gpio: GPIO[32]| InputEn: 1| OutputEn: 1| OpenDrain: 1| Pullup: 1| Pulldown: 0| Intr:0  [0m
 [0;32mI (86359) gpio: GPIO[33]| InputEn: 1| OutputEn: 1| OpenDrain: 1| Pullup: 1| Pulldown: 0| Intr:0  [0m
 [31m[ERROR 1970-01-01 00:01:25 DST:0] [0m  : Failed to start bme, Please check the cables and connections.
 [0;31mE (86469) esp-tls: couldn't get hostname for :grafana.altermundi.net: getaddrinfo() returns 202, addrinfo=0x0 [0m
 [0;31mE (86469) TRANSPORT_BASE: Failed to open a new connection: 32769 [0m
 [0;31mE (86479) HTTP_CLIENT: Connection failed, sock < 0 [0m
 [0;31mE (86539) esp-tls: couldn't get hostname for :grafana.altermundi.net: getaddrinfo() returns 202, addrinfo=0x0 [0m
 [0;31mE (86539) TRANSPORT_BASE: Failed to open a new connection: 32769 [0m
[!] Failed to start bme, Please check the cables and connections. [0;31mE (86539) HTTP_CLIENT: Connection failed, sock < 0 [0m

 [34m[TRACE 1970-01-01 00:01:26 DST:0] [0m  :  t:99.9 h:99.9 p:99.9
 [34m[TRACE 1970-01-01 00:01:26 DST:0] [0m  :  Humydity 99.9 min:60 max:70 humidifier false
 [34m[TRACE 1970-01-01 00:01:26 DST:0] [0m  : turn hum off
 [33m[WARN  1970-01-01 00:01:26 DST:0] [0m  : humidifier current_time 86.110672
 [33m[WARN  1970-01-01 00:01:26 DST:0] [0m  : humidifier enabled
 [33m[WARN  1970-01-01 00:01:26 DST:0] [0m  : humidifier pin turned off--------------------
 [34m[TRACE 1970-01-01 00:01:26 DST:0] [0m  :  temp 99.9 min:37.3 max:37.8
 [34m[TRACE 1970-01-01 00:01:26 DST:0] [0m  : temp actual  99.9 , max  37.8 ,min  37.3 ,resitor status  false
 [34m[TRACE 1970-01-01 00:01:26 DST:0] [0m  : turn resistor off
 [0;33mW (86909) http: esp_http_client_perform returned error 28674 [0m
 [0;33mW (86919) http: esp_http_client_perform returned error 28674 [0m
 [0;33mW (86919) http: esp_http_client_perform returned error 28674 [0m
 [0;33mW (86929) http: esp_http_client_perform returned error 28674 [0m
 [0;33mW (86929) http: esp_http_client_perform returned error 28674 [0m
table: 0x3ffcc048
201
default_ssid
 [34m[TRACE 1970-01-01 00:01:26 DST:0] [0m  :
WiFi connection to AP(default_ssid) has failed!
 [34m[TRACE 1970-01-01 00:01:26 DST:0] [0m  : Disconnect reason: 201
 [34m[TRACE 1970-01-01 00:01:26 DST:0] [0m  : Retrying connection...(attempt 8 of 10)
error de loggg -28674
 [33m[WARN  1970-01-01 00:01:26 DST:0] [0m  : Fail to send Alert to Grafana code return: -28674
 [33m[WARN  1970-01-01 00:01:26 DST:0] [0m  : Fail to send data to grafana code returned : -28674
error de loggg -28674
 [33m[WARN  1970-01-01 00:01:26 DST:0] [0m  : Fail to send Alert to Grafana code return: -28674

```

JereC4str0, 2024-11-14:
#123

Closed 2024-12-20.

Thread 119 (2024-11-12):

iniciales deberia ser el nombre de la incubadora

javierbrk, 2024-11-12:
las iniciales deberian ser el nombre de la incubadora, es lo que veniamos usando para identificarlas
ese nombre deberia ser el mismo que se vea en grafana en el ssid etc

JereC4str0, 2024-11-12:
no habiamos dicho que el nombre iba a ser la MAC adress ?

JereC4str0, 2024-11-14:
#121

Closed 2025-01-31.

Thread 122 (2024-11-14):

problema de inicio en incuabadora con placa olivia control v2

javierbrk, 2024-11-14:
Cuando la pc esta conectada al programador, y el programador a la placa. Todo funciona.

cuando la pc es desconectada del programador pero este sigue enchufado la incubadora no funciona. no se conecta a la red wifi, llega a levantar el ap propio pero parece reiniciarce indefinidamente.

Probablemente por falta de energía

Pablomonte, 2025-02-05:
## Otro de los misterios del universo...
Luego de standarizar el conexionado de los programadores no volvimos a ver este tipo de errores, se cierra el caso por ahora hasta nuevo aviso.

Closed 2025-02-05.

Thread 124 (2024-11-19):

nombre de la incubadora demasiado largo

javierbrk, 2024-11-19:
Esta pull introdujo un error el nombre de la incubadora quedo muy largo y no permite cambiar las configuraciones. no funciona el método config post

https://github.com/AlterMundi-MonitoreoyControl/Proyecto-Incubadora/pull/113

la incubadora no debería tener un nombre que no pueda recibir.

CORRER LAS PRUEBAS UNITARIAS ANTES DE HACER PULL Y ANTES DE APROBARLOS

JereC4str0, 2024-11-21:
#129

JereC4str0, 2024-12-02:
#147

Closed 2024-12-20.

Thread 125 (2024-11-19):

el config de la app podria recibir la respuesta y mostrar porque esta fallando el post

javierbrk, 2024-11-19:
cuando el nombre de la incubadora es muy largo no deja cambiar los parametros pero la app no lo muesta
es posible mostar el resultado del post ? para indicar posibles errores

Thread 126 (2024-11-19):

icono de la app y metadata

javierbrk, 2024-11-19:
seria deseable ponerle el ícono a la app de android ahora es el logo de flutter

javierbrk, 2025-01-31:
https://www.youtube.com/watch?v=RjNAxwcP3Tc
Dejo este video sobre como poner un ícono en la app android de flutter

javierbrk, 2025-01-31:
otra opcion usando android studio parece mas facil, pero usar android studio requiere de descargar toneladas de Bytes https://medium.com/@hemantkumarceo001/day-37-how-to-create-a-custom-launcher-icon-for-your-flutter-app-38036270f0c6

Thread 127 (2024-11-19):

faltaria un scroll en la app para poder ver los  campos que estan mas abajo

javierbrk, 2024-11-19:
en la pantalla de configuración solo puedo ver hasta días de incubación b1
se que hay mas cosas abajo pero no las puedo ver

AnnieScigliano, 2024-11-22:
- Scroll en Config
- Scroll en Redes
- Sized Box en Temp/Hum

javierbrk, 2025-01-31:
esto ya esta resuelto no ?

Closed 2025-02-05.

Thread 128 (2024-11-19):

instalar la app en celus personales y hacer pruebas

javierbrk, 2024-11-19:
**Poner un esp con el main** asegurarse de formatear todo antes de arrancar

instalar la aplicación en el celular

conectarse al wifi de la incubadora
Navegar por las pantallas y verificar que funciona:

- temp y humedad
- redes wifi
- configuración
- fecha de inicio de incubación

reportar problemas

JereC4str0, 2024-12-20:
que pasa con la gente que tiene IOS?

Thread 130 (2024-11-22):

refresh

AnnieScigliano, 2024-11-22:
las views deberían tener un timer para actualizar los datos cada determinado tiempo

https://stackoverflow.com/questions/61954029/how-to-set-a-timer-to-update-api-data-periodically-in-flutter

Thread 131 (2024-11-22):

guardar datos de manera local en flutter

javierbrk, 2024-11-22:
seria util guardar datos como el hash y nombre de la incubadora, el ultimo ip ...
el nombre de la incubadora se puede usar para acceder desde la lan, el hash para resuscribirse a notificaciones,

http://as-esp32.lan/actual

javierbrk, 2025-02-13:
se podria intentar consultar a la ip fija, y a la url de arriba. como esta ahora sería http://<hash>.lan/actual eso te permite estar conectado a la red wifi en la que existe internet y esta conectado también la incubadora.
solo funcionará en routers con poca seguridad, sin aislacion entre clientes.

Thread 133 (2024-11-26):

Implementar test de control al iniciar la incubadora

fabriciopetiso, 2024-11-26:
Se requiere la implementación de un test de control automático que se ejecute al encender la incubadora para verificar el correcto funcionamiento de sus componentes principales: resistencia (fuente de calor), sistema de humedad y mecanismo de volteo.

Encender la resistencia y validar que alcance un nivel mínimo de calentamiento.
Confirmar que la temperatura medida por el sensor esté dentro de los límites establecidos en un tiempo razonable.

Prueba del sistema de humedad:
Activar el sistema de generación de humedad y verificar que el sensor registre un aumento de humedad.

Prueba del mecanismo de volteo:
Ejecutar el sistema de volteo y confirmar que complete un ciclo de movimiento en ambos sentidos.
Detectar errores en el giro o en la finalización del ciclo.

javierbrk, 2024-11-28:
https://github.com/AlterMundi-MonitoreoyControl/Proyecto-Incubadora/blob/main/src/embedded/test/TESTING.md

javierbrk, 2024-11-28:
ver que cuando termine la prueba inicial la rotacion quede a 90°

javierbrk, 2025-01-10:
el main ya cuenta con una prueba de rotación solo si la rotación funciona arranca el resto, faltaría temperatura y humedad

javierbrk, 2025-02-05:
temperatura y humedad tienen una verificación

Closed 2025-02-05.

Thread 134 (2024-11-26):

Paneles de grafana Independientes para cada Incubadora/ Sensor / Monitoreo

fabriciopetiso, 2024-11-26:
Necesitamos ir perfilando que cada artefacto tenga su panel de grafana independiente, para optimizar las alarmas y la visualización.ç

Pablomonte, 2025-02-05:
pusimos un selector de incubadora en el tablero https://grafana.altermundi.net/d/2ebcKhKHz/visor-incubadoras-librepollo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
Las alertas Ntfy se propagan por cada incubadora

Closed 2025-02-05.

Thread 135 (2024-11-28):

problema mecanico de rotación

javierbrk, 2024-11-28:
acople del carretel con motor
sensores que se despegan

javierbrk, 2024-11-28:
darle un poco mas de cuerpo al carretel

Pablomonte, 2025-01-15:
Los nuevos motores de rotación con eje de 8mm y perforación para chaveta resolvieron este problema

Closed 2025-01-15.

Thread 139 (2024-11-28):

alarmas

javierbrk, 2024-11-28:
ADVERTENCIA
humidificador
Día 17 de incubación:

ERROR
temperatura mas de 43
temperatura no cambia
humedad no cambia
falla en rotación
humedad baja (mas de una hora debajo de la establecida)

JereC4str0, 2024-12-20:
en la primera advertencia, que deberia avisar sobre el humidificador?

JereC4str0, 2024-12-20:
estamos hablando de grafana o es un control mediante firmware?

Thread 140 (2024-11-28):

disipadores para los triacs

javierbrk, 2024-11-28:
usar los recortes de las planchas de aluminio para poner disipadores a los triacs

Pablomonte, 2025-01-15:
Cortar con amoladora flejes de aluminio de 2cm de ancho y 4,7 cm aprox de largo para doblarlos a 90° en 3 partes formando una "U". Perforar en el centro como para atornillar a los triacs
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

O Comprarlos y pare de sufrir..:
https://articulo.mercadolibre.com.ar/MLA-1444379970-10-kit-disipadores-para-to-220-con-aislante-niple-y-tornillo-_JM

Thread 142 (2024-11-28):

tapa/caja para la rotación

javierbrk, 2024-11-28:
La rotación esta muy expuesta y además se genera un flujo de aire frio que entra en la incu. Es necesario cerrar todo para que no le llegue basura tampoco.

Closed 2025-02-13.

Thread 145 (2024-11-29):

Bug en pruebas unitarias

JereC4str0, 2024-11-29:
El tiempo(delay) entre peticion en las pruebas unitarias es muy corto, esto hace que no se reflejen los cambios y falle por mas que sea valida la prueba

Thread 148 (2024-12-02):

Problema al cargar tiempo de bandejas

JereC4str0, 2024-12-02:
en la funcion set_incubator_period falta un simbolo  igual, la idea era acomodarlo al formato epoch pero solo aceptaria 9 caracteres
cuando intenté setear 1234567890 como tiempo de bandejas en las pruebas unitarias esto devolvio "error setting incubation_period"

esta es la [linea](https://github.com/AlterMundi-MonitoreoyControl/Proyecto-Incubadora/blob/284fb6cefef7873510b75ba8a1400946046ee40c/src/embedded/app/incubator.lua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)

javierbrk, 2024-12-04:
en que unidades debería ingresarse el período ? en segundos ?

¿ cuanto es el período máximo ? ... un año

en caso de que sea segundos y el tiempo máximo de incubación sea un año ...

365d24h3600s = 31536000 s ... para un año serían 8 caracteres

creo que no es un problema ...

Closed 2024-12-06.

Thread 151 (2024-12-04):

wifi not conecting

javierbrk, 2024-12-04:
Al utilziar el firmware de la rama principal  @Santiagocetran  no pudo conectar el esp a su red...  necesita asistencia, @JereC4str0  podes ayudar con esto ?
Coordinen una reunión para destrabar esta situación @Santiagocetran @JereC4str0

JereC4str0, 2024-12-11:
#155 intento solucionar esto en esta PR

JereC4str0, 2024-12-11:
A.M.A

Closed 2024-12-20.

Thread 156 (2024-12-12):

Montaje del sensor bme

javierbrk, 2024-12-12:
El sensor bme suele fallar cuando el cable es muy largo o cuando esta flojo alguno de los conectores.
Falta definir la estructura de fijación, conexionado , largo del cable

JereC4str0, 2024-12-20:
le pasé la datashet a claude, me tiró cosas interesantes:

specificaciones de interfaz:

    Para la interfaz I²C, la capacitancia de carga del bus (Cb) en SDA y SCK no debe superar los 400 pF.
    Tanto la interfaz I²C como la SPI tienen especificaciones de temporización detalladas que deben cumplirse para un funcionamiento fiable.

    Compatibilidad con interfaces digitales:

    I²C hasta 3,4 MHz
    SPI hasta 10 MHz (en configuraciones de 3 y 4 hilos)

    Consideraciones sobre la alimentación:

    El rizado de VDD debe ser como máximo de 50 mVpp
    Rango de funcionamiento de VDD: 1,71V a 3,6V
    Rango de funcionamiento de VDDIO: 1,2V a 3,6V

    Montaje físico:

    El espacio libre por encima de la tapa metálica debe ser de 0,1 mm como mínimo.
    Es necesario prever una ventilación adecuada para la medición de la presión ambiente
    Los líquidos no deben entrar en contacto directo con el dispositivo

    Mantener los cables tan cortos como sea posible para minimizar la carga capacitiva.
    Tener en cuenta la capacitancia total del bus (debe ser inferior a 400 pF para I²C).
    Seguir buenas prácticas de diseño para minimizar el ruido y las interferencias.
    Utilice resistencias de pull-up adecuadas para I²C (el valor típico sugerido es de 4,7 kΩ).

Closed 2025-01-10.

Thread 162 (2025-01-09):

no es posible correr las pruebas unitarias

javierbrk, 2025-01-09:
module 'http_request_methods' not found:

@JereC4str0 no estoy encontrando esta dependencia del archivo test rest api

javierbrk, 2025-02-05:
cuales son las dependencias para correr las pruebas de manera local ?

javierbrk, 2025-02-13:
@JereC4str0 podrias mencionar cuales son las dependencias necesarias para poder correr las pruebas ?

JereC4str0, 2025-05-17:
http_request methods era un modulo viejo que tenia los handlers para las peticiones web, ahora esta todo junto en un mismo archivo, esa linea quedó importando algo que no existe, con eliminar esa linea ya podrias correr las pruebas sin problema

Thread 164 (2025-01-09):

no existe la posiblidad de cambiar la frecuencia de rotación desde la app

javierbrk, 2025-01-09:

AnnieScigliano, 2025-02-11:
https://github.com/AlterMundi-MonitoreoyControl/Proyecto-Incubadora/pull/195

javierbrk, 2025-02-13:
este cambio requiere de reiniciar la incubadora. @AnnieScigliano mencionar este requisito en la documentación.

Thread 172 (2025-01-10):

la app de android no puede vincularse con algunos celus al esp32

javierbrk, 2025-01-10:
En algunos celus, la conección con el esp32 no es estable. El problema parece ser porque no tiene internet. Entonces es necesario pedirle que se quede conectado a la red (1) y en algunos casos desactivar el paquete de datos (2).

| modelo de celu | version de android | datos activados | otras wifis al alcance | app funciona |
|----------------|--------------------|-----------------|------------------------|--------------|
| redmi 7a       | 14                 | no              | si                     | si           |
| redmi 7a       | 14                 | si              | si                     | no           |
| moto e7i power | 10                 | no              | si                     | si           |

Cosas a probar para mejorar:
para resolver 2 se puede usar esto que es para atar las peticiones de una app en particular a una interfaz.
https://developer.android.com/reference/android/net/ConnectivityManager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

javierbrk, 2025-02-05:
@fabriciopetiso  podes listar los celus en los que te funciona y los que no funciona ?

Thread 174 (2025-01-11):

agregar errores en las notificaciones de la app

javierbrk, 2025-01-11:
en el endpoint de actual podemos ver los ultimos errores disponibles, mostrarlos al presionar la campanita,  ... tambien se pude poner abajo de la humedad ... como lista. ..
en esta pull se puede ver un ejemplo de la lista de errores, cada error tiene una marca de tiempo y un texto
https://github.com/AlterMundi-MonitoreoyControl/Proyecto-Incubadora/pull/173

javierbrk, 2025-01-31:
lisssstooo quedo barbaro

Closed 2025-01-31.

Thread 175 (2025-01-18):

min y max de humedad no impactan

fabriciopetiso, 2025-01-18:
En una de las incubadoras, a través de la app no impactan las modificaciones en la Esp
Lo raro es que cambiando el configurator a mano, el config.json levanta los datos pero no llegan al comportamiento de la esp. En el ESplorer con la incu andando se ven las max y min distinas a las del config.json

javierbrk, 2025-02-04:
@AnnieScigliano podes verificar que la app ponga primero el max y luego el min de humedad en el json ?

javierbrk, 2025-02-05:
se debe cambiar primero el maximo

Closed 2025-02-13.

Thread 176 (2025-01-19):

cuando se cambian las credenciales de wifi pero hay un error ese error no se corrige en el config .json

javierbrk, 2025-01-19:
si la incubadora estaba conectada a un wifi,
luego la cambia a otro wifi con las credenciales equivocadas usando la api
las credenciales incorrectas se graban en el config
el wifi va a tratar de conectarse, no va a poder, va a revertir las credenciales a las viejas pero el config va a seguir teniendo las credenciales in correctas.
Al reiniciar la incubadora va a tener credenciales incorrectas y no va a poder conectarsee

javierbrk, 2025-01-31:
resuelto

Closed 2025-01-31.

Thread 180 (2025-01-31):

como hacer para que un usuario solo acceda a una incubadora

javierbrk, 2025-01-31:

javierbrk, 2025-02-05:
pusimos un selector de incubadora en el tablero https://grafana.altermundi.net/d/2ebcKhKHz/visor-incubadoras-librepollo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

Closed 2025-02-05.

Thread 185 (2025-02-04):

humedad dia 18 a 21

javierbrk, 2025-02-04:
Hasta el día 18 Min 55 max 65. (promedio 60) . Del 18 al 21 de cada bandeja ( min 65 y max 75) promedio 70

podemos decir que si el día es 18-21 de cualquier bandeja haga hum_min=hum_min+10 ? y lo mismo con la max ?

javierbrk, 2025-02-05:
listo

Closed 2025-02-05.

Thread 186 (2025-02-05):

wifi apagado encender incu, no se conecta mas ??

javierbrk, 2025-02-05:

javierbrk, 2025-02-05:
hicimos una prueba donde no se reconectaba, luego hicimos otra prueba y se conectó

javierbrk, 2025-02-11:
```
NodeMCU ESP32 build 2024-12-04 22:59 powered by Lua 5.1.4 [5.1-doublefp] on IDF v5.1.3
 [0;32mI (984) gpio: GPIO[27]| InputEn: 0| OutputEn: 1| OpenDrain: 0| Pullup: 0| Pulldown: 0| Intr:0  [0m
 [0;32mI (984) gpio: GPIO[13]| InputEn: 0| OutputEn: 1| OpenDrain: 0| Pullup: 0| Pulldown: 0| Intr:0  [0m
 [0;32mI (1004) gpio: GPIO[17]| InputEn: 0| OutputEn: 1| OpenDrain: 0| Pullup: 0| Pulldown: 0| Intr:0  [0m
 [0;32mI (1134) gpio: GPIO[27]| InputEn: 0| OutputEn: 1| OpenDrain: 0| Pullup: 0| Pulldown: 0| Intr:0  [0m
 [0;32mI (1144) gpio: GPIO[13]| InputEn: 0| OutputEn: 1| OpenDrain: 0| Pullup: 0| Pulldown: 0| Intr:0  [0m
 [0;32mI (1154) gpio: GPIO[17]| InputEn: 0| OutputEn: 1| OpenDrain: 0| Pullup: 0| Pulldown: 0| Intr:0  [0m
 [0;32mI (2134) phy_init: phy_version 4791,2c4672b,Dec 20 2023,16:06:06 [0m
I (2214) wifi:mode : sta (30:c6:f7:21:f7:50) + softAP (30:c6:f7:21:f7:51)
I (2214) wifi:enable tsf
I (2224) wifi:Total power save buffer number: 16
I (2224) wifi:Init max length of beacon: 752/752
I (2224) wifi:Init max length of beacon: 752/752
 [34m[TRACE 1970-01-01 00:00:01 DST:0] [0m  : [W] No WiFi credentials provided. Please configure WiFi settings.
 [0;32mI (2524) gpio: GPIO[32]| InputEn: 1| OutputEn: 1| OpenDrain: 1| Pullup: 1| Pulldown: 0| Intr:0  [0m
 [0;32mI (2524) gpio: GPIO[33]| InputEn: 1| OutputEn: 1| OpenDrain: 1| Pullup: 1| Pulldown: 0| Intr:0  [0m
 [0;32mI (2804) gpio: GPIO[2]| InputEn: 0| OutputEn: 1| OpenDrain: 0| Pullup: 0| Pulldown: 0| Intr:0  [0m
 [0;32mI (2804) gpio: GPIO[13]| InputEn: 0| OutputEn: 1| OpenDrain: 0| Pullup: 0| Pulldown: 0| Intr:0  [0m
 [0;32mI (2814) gpio: GPIO[15]| InputEn: 0| OutputEn: 1| OpenDrain: 0| Pullup: 0| Pulldown: 0| Intr:0  [0m
 [0;32mI (2824) gpio: GPIO[17]| InputEn: 0| OutputEn: 1| OpenDrain: 0| Pullup: 0| Pulldown: 0| Intr:0  [0m
 [0;32mI (2824) gpio: GPIO[27]| InputEn: 0| OutputEn: 1| OpenDrain: 0| Pullup: 0| Pulldown: 0| Intr:0  [0m
 [0;32mI (2854) gpio: GPIO[34]| InputEn: 1| OutputEn: 0| OpenDrain: 0| Pullup: 1| Pulldown: 0| Intr:0  [0m
 [0;32mI (2854) gpio: GPIO[35]| InputEn: 1| OutputEn: 0| OpenDrain: 0| Pullup: 1| Pulldown: 0| Intr:0  [0m
 [34m[TRACE 1970-01-01 00:00:02 DST:0] [0m  : Configurator status:  {"hash":true,"min_temp":true,"tray_two_date":true,"incubator_name":true,"rotation_duration":true,"tray_three_date":true,"min_hum":true,"max_hum":true,"max_temp":true,"incubation_period":true,"tray_one_date":true,"rotation_period":true}
 [34m[TRACE 1970-01-01 00:00:02 DST:0] [0m  : [R] at least one sensor is active not activating rotation
starting server .. fyi maxtemp 37.8
>  [0;32mI (3474) esp_netif_lwip: DHCP server started on interface WIFI_AP_DEF with IP: 192.168.16.10 [0m
 [34m[TRACE 1970-01-01 00:00:05 DST:0] [0m  : [W] WiFi disconnected from AP(OpenWrt). Reason: 201
 [34m[TRACE 1970-01-01 00:00:05 DST:0] [0m  : [W] Attempting reconnection... (1/10)
 [34m[TRACE 1970-01-01 00:00:18 DST:0] [0m  : [W] WiFi disconnected from AP(OpenWrt). Reason: 201
 [34m[TRACE 1970-01-01 00:00:18 DST:0] [0m  : [W] Attempting reconnection... (2/10)
 [31m[ERROR 1970-01-01 00:00:32 DST:0] [0m  : [W] New credentials validation failed, reverting to previous configuration...
 [0;31mE (33174) esp-tls: couldn't get hostname for :grafana.altermundi.net: getaddrinfo() returns 202, addrinfo=0x0 [0m
 [0;31mE (33174) transport_base: Failed to open a new connection: 32769 [0m
 [0;31mE (33194) HTTP_CLIENT: Connection failed, sock < 0 [0m
 [0;31mE (33234) esp-tls: couldn't get hostname for :ntfy.sh: getaddrinfo() returns 202, addrinfo=0x0 [0m
 [0;31mE (33234) transport_base: Failed to open a new connection: 32769 [0m
 [0;31mE (33244) HTTP_CLIENT: Connection failed, sock < 0 [0m
 [0;33mW (33244) http: esp_http_client_perform returned error 28674 [0m
 [0;33mW (33254) http: esp_http_client_perform returned error 28674 [0m
error de loggg -28674
 [34m[TRACE 1970-01-01 00:00:32 DST:0] [0m  : Failed to send notification: -28674
 [34m[TRACE 1970-01-01 00:00:36 DST:0] [0m  : [W] WiFi disconnected from AP(OpenWrt). Reason: 201
I (45654) wifi:new:<11,2>, old:<11,2>, ap:<11,2>, sta:<0,0>, prof:11
I (45654) wifi:station: 18:5e:0f:e9:19:93 join, AID=1, bgn, 40D
``

javierbrk, 2025-02-13:
hice un par de cambios y ya no sucede ... no logro reproducirlo

Closed 2025-02-13.

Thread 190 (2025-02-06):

en la app en el boton de grafana poner la url a la pagina web que se construye como se muestra abajo

javierbrk, 2025-02-06:
actualmente grafana no funciona, no tenemos instancia propia,...
poner mientrastanto

[https://grafana.altermundi.net/d/2ebcKhKHz/visor-incubadoras-librepollo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](https://grafana.altermundi.net/d/2ebcKhKHz/visor-incubadoras-librepollo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)

donde "incu-30c6f721f750" es el nombre de la incubadora

AnnieScigliano, 2025-02-09:
https://github.com/AlterMundi-MonitoreoyControl/Proyecto-Incubadora/pull/193

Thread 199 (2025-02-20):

Humedad demasiado alta en algunas incubadoras

javierbrk, 2025-02-20:
en el firmware implemente el control de diías para subir la humedad de esta manera. Esto implica que incubation_period debe ser = 18

        local function is_in_high_humidity_period(days)
            return days >= incubator.incubation_period and days <= 21
        end

en la app el texto de ese campo dice "dias del proceso" que deberia ser 21...

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

para salir del paso se puede cambiar el label a :

"dias de incubacion para iniciar aumento de humedad"

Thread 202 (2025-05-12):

Problema Sensor BME - Rotación OK.. Incu 10

fabriciopetiso, 2025-05-12:
La rotacion ahora esta ok, pero no inicializa el BME
dejo el log

[log incu 10 bme.txt](https://github.com/user-attachments/files/20174517/log.incu.10.bme.txt)

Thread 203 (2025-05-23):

Monitoreos de CO2 - "saltos o picos" En datos

fabriciopetiso, 2025-05-23:
Todos los monitoreos de CO2 muestran en grafana "saltos" en los valores que parece o problema de HW (tipo falso contacto) o problema de SW.
https://grafana.altermundi.net/d/ekKppCrIk/co2-comparacion-de-sensores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
ahí un registro

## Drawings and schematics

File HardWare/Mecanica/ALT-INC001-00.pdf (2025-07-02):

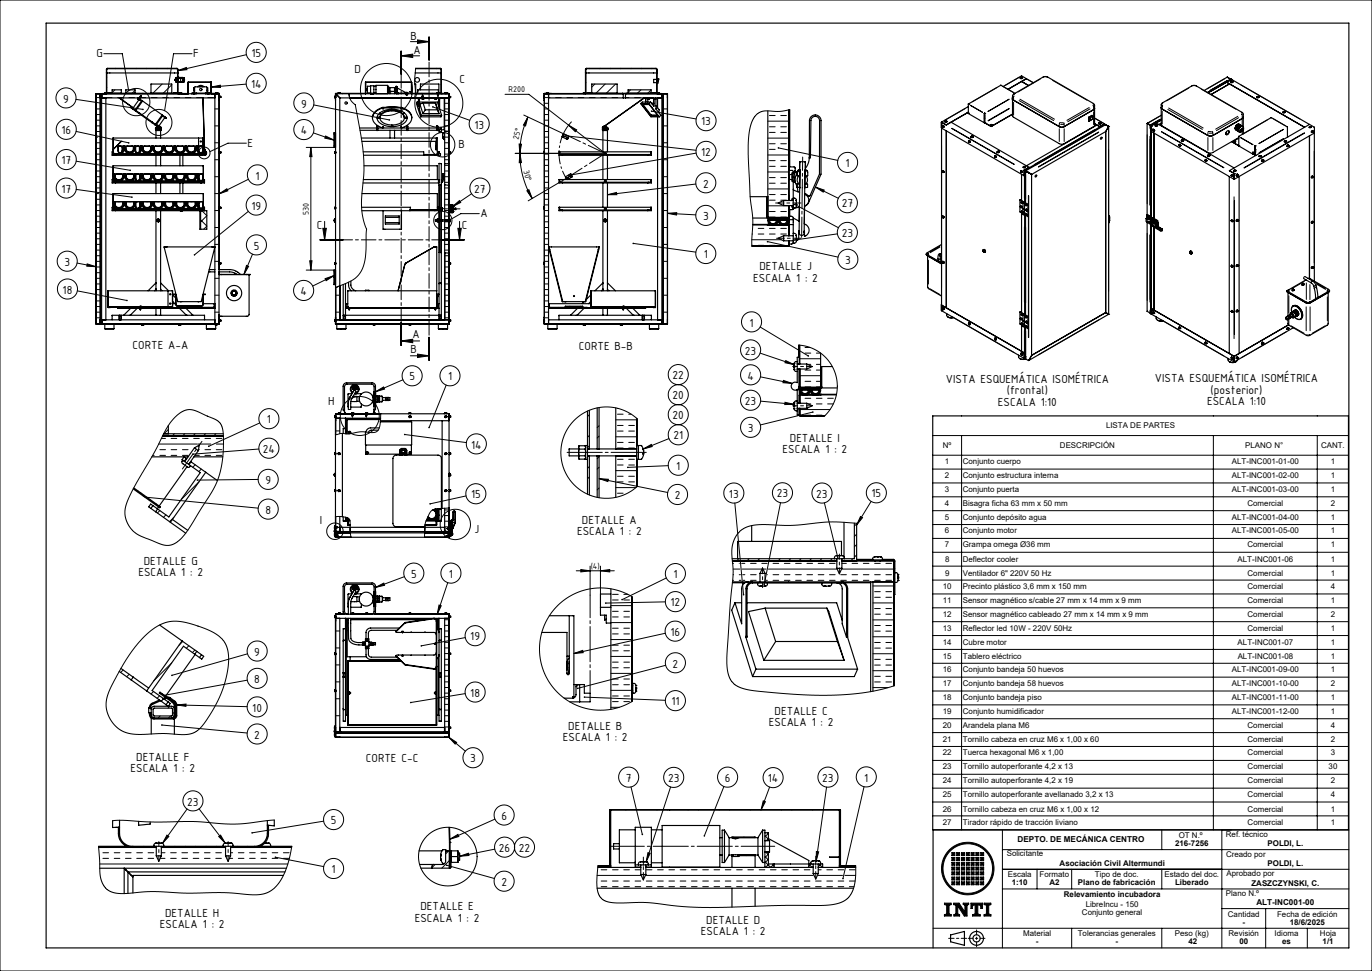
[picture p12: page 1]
CORTE A-A; DETALLE A ESCALA 1 : 2; DETALLE I ESCALA 1 : 2; DETALLE H ESCALA 1 : 2; DETALLE D ESCALA 1 : 2; DETALLE F ESCALA 1 : 2; DETALLE G ESCALA 1 : 2; DETALLE C ESCALA 1 : 2; CORTE B-B; DETALLE B ESCALA 1 : 2; CORTE C-C5; DETALLE E ESCALA 1 : 2; DETALLE J ESCALA 1 : 2; ESCALA 1:10; DESCRIPCIÓN; PLANO N°; CANT. 1; Conjunto cuerpo; ALT-INC001-01-00; Conjunto estructura interna; ALT-INC001-02-00; Conjunto puerta; ALT-INC001-03-00; Bisagra ficha 63 mm x 50 mm; Comercial; Conjunto depósito agua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

VISTA ESQUEMÁTICA ISOMÉTRICA

LISTA DE PARTES

10 | Precinto plástico 3,6 mm x 150 mm | Comercial | 4
11 | Sensor magnético s/cable 27 mm x 14 mm x 9 mm | Comercial | 1
12 | Sensor magnético cableado 27 mm x 14 mm x 9 mm | Comercial | 2
13 | Reflector led 10W - 220V 50Hz | Comercial | 1
14 | Cubre motor | ALT-INC001-07 | 1
15 | Tablero eléctrico | ALT-INC001-08 | 1
16 | Conjunto bandeja 50 huevos | ALT-INC001-09-00 | 1
17 | Conjunto bandeja 58 huevos | ALT-INC001-10-00 | 2
18 | Conjunto bandeja piso | ALT-INC001-11-00 | 1
19 | Conjunto humidificador | ALT-INC001-12-00 | 1
20 | Arandela plana M6 | Comercial | 4
21 | Tornillo cabeza en cruz M6 x 1,00 x 60 | Comercial | 2
22 | Tuerca hexagonal M6 x 1,00 | Comercial | 3
23 | Tornillo autoperforante 4,2 x 13 | Comercial | 30
24 | Tornillo autoperforante 4,2 x 19 | Comercial | 2
25 | Tornillo autoperforante avellanado 3,2 x 13 | Comercial | 4
26 | Tornillo cabeza en cruz M6 x 1,00 x 12 | Comercial | 1
27 | Tirador rápido de tracción liviano | Comercial | 1

DEPTO. DE MECÁNICA CENTRO | OT N.º 216-7256 | Ref. técnico POLDI, L.
Solicitante Asociación Civil Altermundi | | Creado por POLDI, L.
Escala 1:10 | Formato A2 | Tipo de doc. Plano de fabricación | Estado del doc. Liberado | Aprobado por ZASZCZYNSKI, C.

Relevamiento incubadora LibreIncu - 150 Conjunto general | | | | Plano N.º ALT-INC001-00

Cantidad - | Fecha de edición 18/6/2025

Material - | Tolerancias generales - | Peso (kg) 42 | Revisión 00 | Idioma es | Hoja 1/1

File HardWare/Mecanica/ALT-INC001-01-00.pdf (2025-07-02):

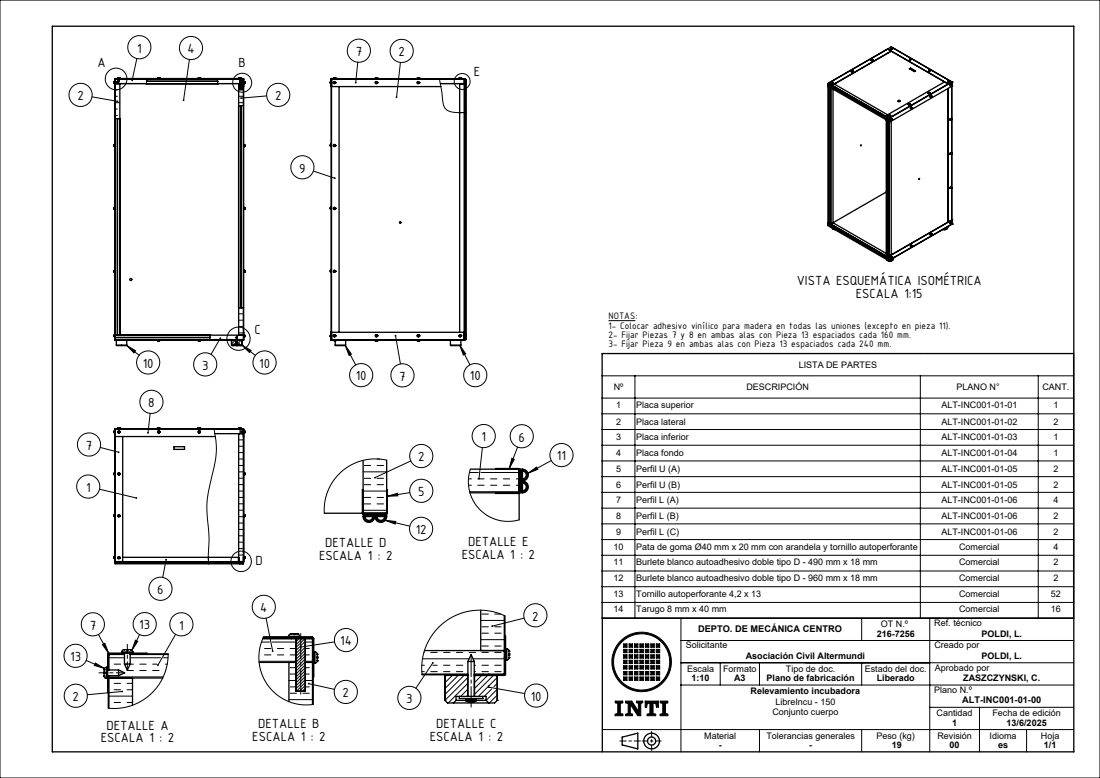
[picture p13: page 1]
DETALLE A ESCALA 1 : 2; DETALLE B ESCALA 1 : 2; DETALLE C ESCALA 1 : 2; DETALLE D ESCALA 1 : 2; DETALLE E ESCALA 1 : 2; ESCALA 1:15

VISTA ESQUEMÁTICA ISOMÉTRICA

NOTAS: 1- Colocar adhesivo vinílico para madera en todas las uniones (excepto en pieza 11).
2- Fijar Piezas 7 y 8 en ambas alas con Pieza 13 espaciados cada 160 mm.
3- Fijar Pieza 9 en ambas alas con Pieza 13 espaciados cada 240 mm.

LISTA DE PARTES

Nº | DESCRIPCIÓN | PLANO N° | CANT.
1 | Placa superior | ALT-INC001-01-01 | 1
2 | Placa lateral | ALT-INC001-01-02 | 2
3 | Placa inferior | ALT-INC001-01-03 | 1
4 | Placa fondo | ALT-INC001-01-04 | 1
5 | Perfil U (A) | ALT-INC001-01-05 | 2
6 | Perfil U (B) | ALT-INC001-01-05 | 2
7 | Perfil L (A) | ALT-INC001-01-06 | 4
8 | Perfil L (B) | ALT-INC001-01-06 | 2
9 | Perfil L (C) | ALT-INC001-01-06 | 2
10 | Pata de goma Ø40 mm x 20 mm con arandela y tornillo autoperforante | Comercial | 4
11 | Burlete blanco autoadhesivo doble tipo D - 490 mm x 18 mm | Comercial | 2
12 | Burlete blanco autoadhesivo doble tipo D - 960 mm x 18 mm | Comercial | 2
13 | Tornillo autoperforante 4,2 x 13 | Comercial | 52
14 | Tarugo 8 mm x 40 mm | Comercial | 16

DEPTO. DE MECÁNICA CENTRO | OT N.º 216-7256 | Ref. técnico POLDI, L.
Solicitante Asociación Civil Altermundi | | Creado por POLDI, L.
Escala 1:10 | Formato A3 | Tipo de doc. Plano de fabricación | Estado del doc. Liberado | Aprobado por ZASZCZYNSKI, C.

Relevamiento incubadora LibreIncu - 150 Conjunto cuerpo | | | | Plano N.º ALT-INC001-01-00

Cantidad 1 | Fecha de edición 13/6/2025

Material - | Tolerancias generales - | Peso (kg) 19 | Revisión 00 | Idioma es | Hoja 1/1

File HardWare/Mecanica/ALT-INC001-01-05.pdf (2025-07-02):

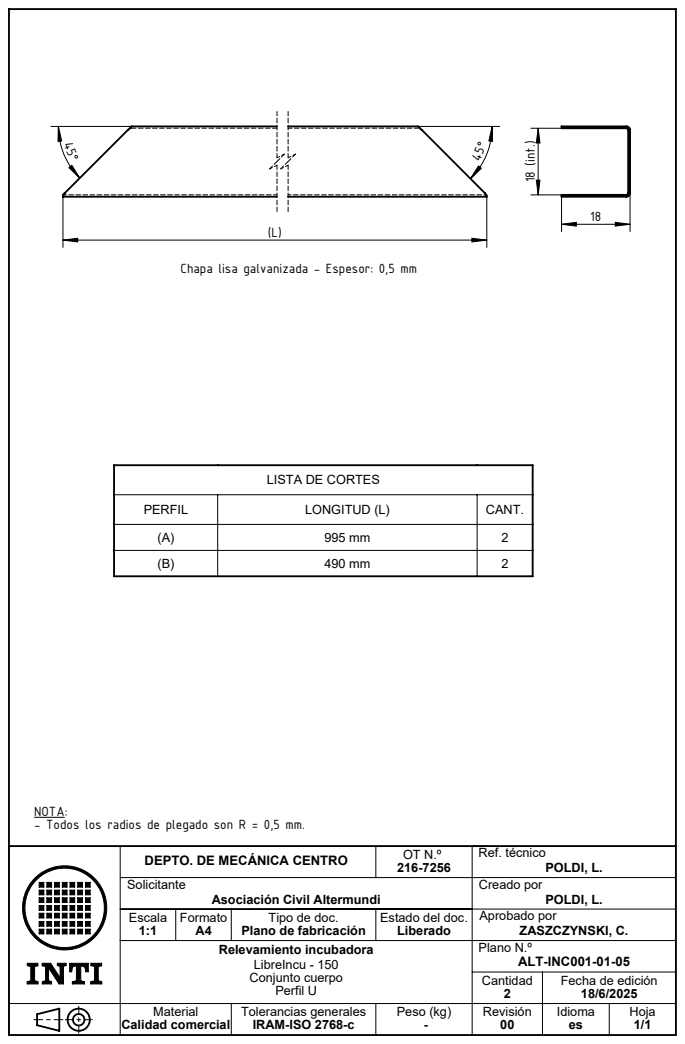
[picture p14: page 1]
18 (int.); Calidad comercial; Peso (kg); Ref. técnico POLDI, L.; Tolerancias generales IRAM-ISO 2768-c

Chapa lisa galvanizada - Espesor: 0,5 mm

LISTA DE CORTES

PERFIL | LONGITUD (L) | CANT.
(A) | 995 mm | 2
(B) | 490 mm | 2

NOTA: - Todos los radios de plegado son R = 0,5 mm.

DEPTO. DE MECÁNICA CENTRO

Solicitante Asociación Civil Altermundi | Creado por POLDI, L.
Escala 1:1 | Formato A4 | Tipo de doc. Plano de fabricación | Estado del doc. Liberado | Aprobado por ZASZCZYNSKI, C.

Relevamiento incubadora LibreIncu - 150 Conjunto cuerpo Perfil U | | | | Plano N.º ALT-INC001-01-05

Cantidad 2 | Fecha de edición 18/6/2025

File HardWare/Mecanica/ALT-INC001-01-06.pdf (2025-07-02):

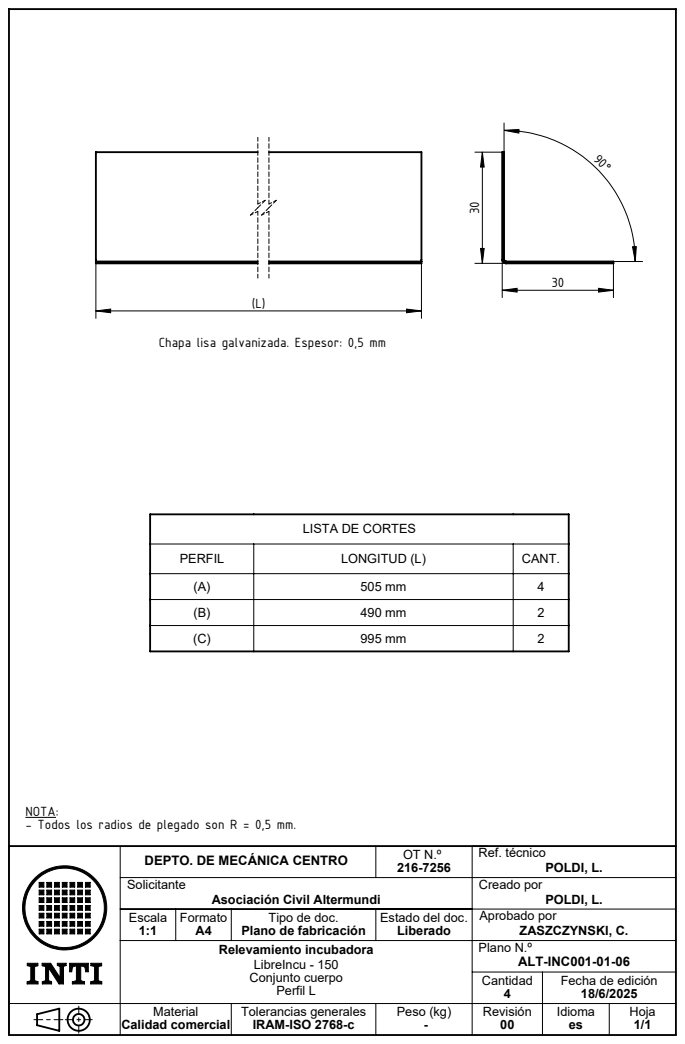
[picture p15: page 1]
Calidad comercial; Peso (kg); Ref. técnico POLDI, L.; Tolerancias generales IRAM-ISO 2768-c

Chapa lisa galvanizada. Espesor: 0,5 mm

LISTA DE CORTES

PERFIL | LONGITUD (L) | CANT.
(A) | 505 mm | 4
(B) | 490 mm | 2
(C) | 995 mm | 2

NOTA: - Todos los radios de plegado son R = 0,5 mm.

DEPTO. DE MECÁNICA CENTRO

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

Relevamiento incubadora LibreIncu - 150 Conjunto cuerpo Perfil L | | | | Plano N.º ALT-INC001-01-06

Cantidad 4 | Fecha de edición 18/6/2025

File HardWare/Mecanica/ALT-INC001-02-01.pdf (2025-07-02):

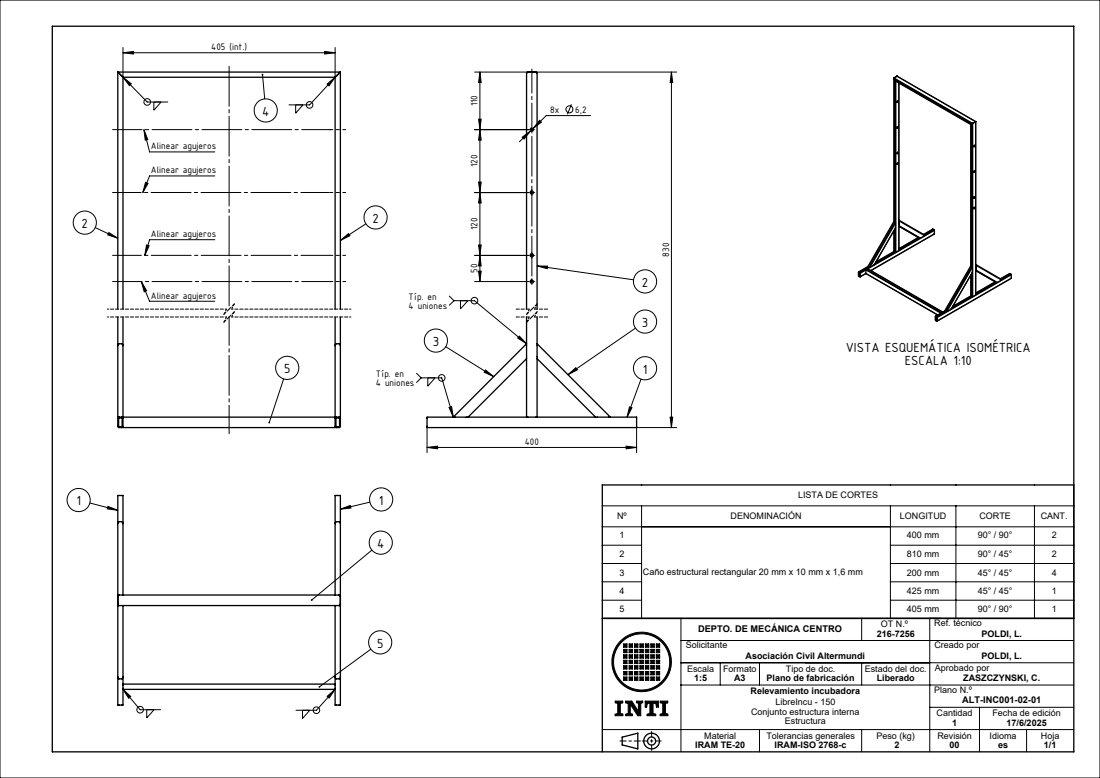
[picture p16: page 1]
405 (int.); Alinear agujeros; Típ. en 4 uniones; ESCALA 1:10

VISTA ESQUEMÁTICA ISOMÉTRICA

LISTA DE CORTES

Nº | DENOMINACIÓN | LONGITUD | CORTE | CANT.
1 | Caño estructural rectangular 20 mm x 10 mm x 1,6 mm | 400 mm | 90° / 90° | 2
2 | | 810 mm | 90° / 45° | 2
3 | | 200 mm | 45° / 45° | 4
4 | | 425 mm | 45° / 45° | 1
5 | | 405 mm | 90° / 90° | 1

DEPTO. DE MECÁNICA CENTRO | OT N.º 216-7256 | Ref. técnico POLDI, L.
Solicitante Asociación Civil Altermundi | | Creado por POLDI, L.
Escala 1:5 | Formato A3 | Tipo de doc. Plano de fabricación | Estado del doc. Liberado | Aprobado por ZASZCZYNSKI, C.

Relevamiento incubadora LibreIncu - 150 Conjunto estructura interna Estructura | | | | Plano N.º ALT-INC001-02-01

Cantidad 1 | Fecha de edición 17/6/2025

Material IRAM TE-20 | Tolerancias generales IRAM-ISO 2768-c | Peso (kg) 2 | Revisión 00 | Idioma es | Hoja 1/1

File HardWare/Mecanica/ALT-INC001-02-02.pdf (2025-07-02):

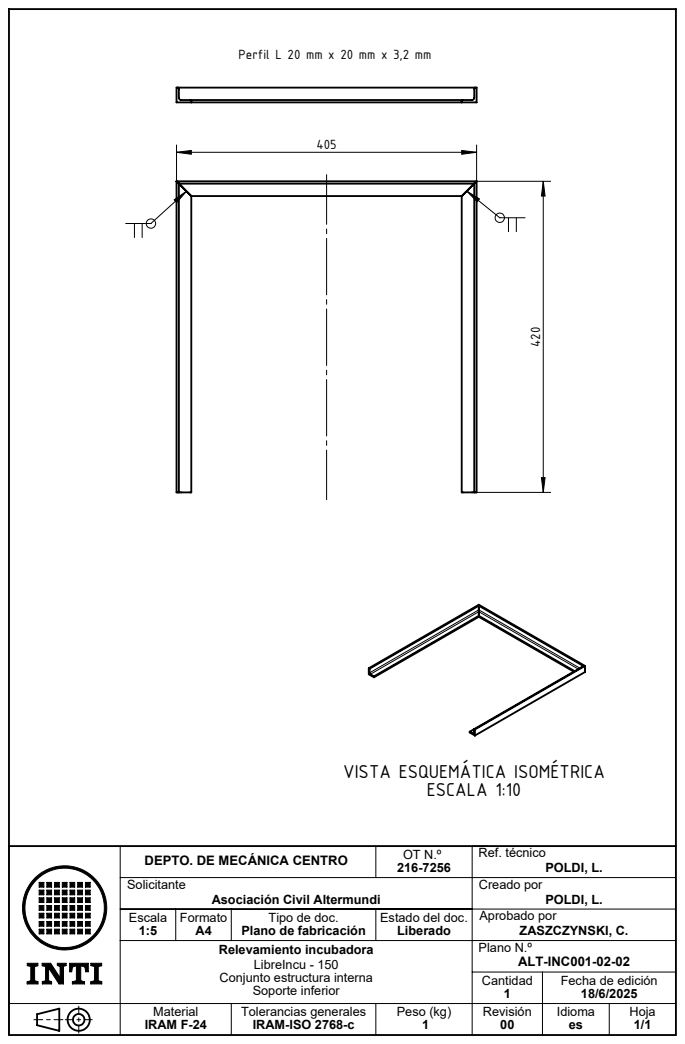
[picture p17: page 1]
ESCALA 1:10; IRAM F-24; Peso (kg); Ref. técnico POLDI, L.; Tolerancias generales IRAM-ISO 2768-c

Perfil L 20 mm x 20 mm x 3,2 mm

VISTA ESQUEMÁTICA ISOMÉTRICA

DEPTO. DE MECÁNICA CENTRO

Solicitante Asociación Civil Altermundi | Creado por POLDI, L.
Escala 1:5 | Formato A4 | Tipo de doc. Plano de fabricación | Estado del doc. Liberado | Aprobado por ZASZCZYNSKI, C.

Relevamiento incubadora LibreIncu - 150 Conjunto estructura interna Soporte inferior | | | | Plano N.º ALT-INC001-02-02

Cantidad 1 | Fecha de edición 18/6/2025

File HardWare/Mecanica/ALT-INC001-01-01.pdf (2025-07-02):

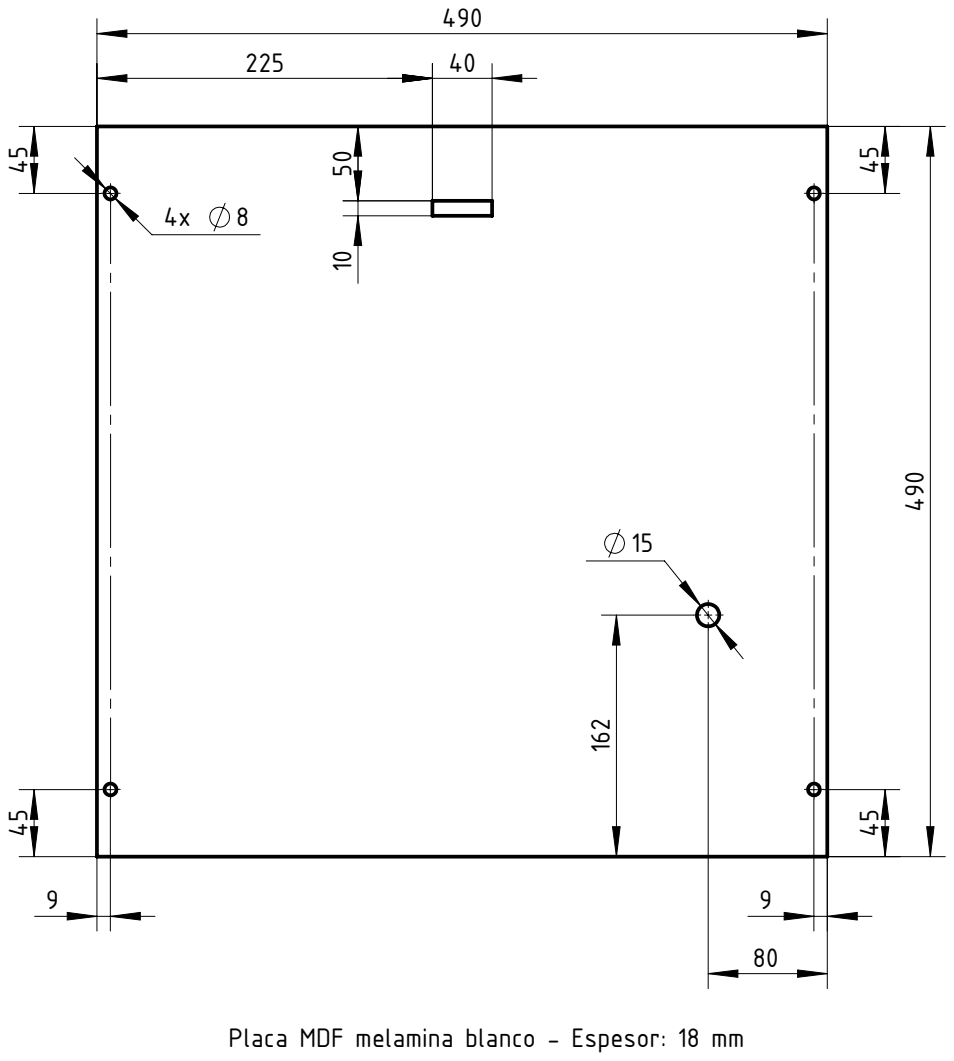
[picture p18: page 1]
Peso (kg); Ref. técnico POLDI, L.; Tolerancias generales IRAM-ISO 2768-c

Placa MDF melamina blanco - Espesor: 18 mm

DEPTO. DE MECÁNICA CENTRO

Solicitante Asociación Civil Altermundi | Creado por POLDI, L.
Escala 1:10 | Formato A4 | Tipo de doc. Plano de fabricación | Estado del doc. Liberado | Aprobado por ZASZCZYNSKI, C.

Relevamiento incubadora LibreIncu - 150 Conjunto cuerpo Placa superior | | | | Plano N.º ALT-INC001-01-01

Cantidad 1 | Fecha de edición 18/6/2025

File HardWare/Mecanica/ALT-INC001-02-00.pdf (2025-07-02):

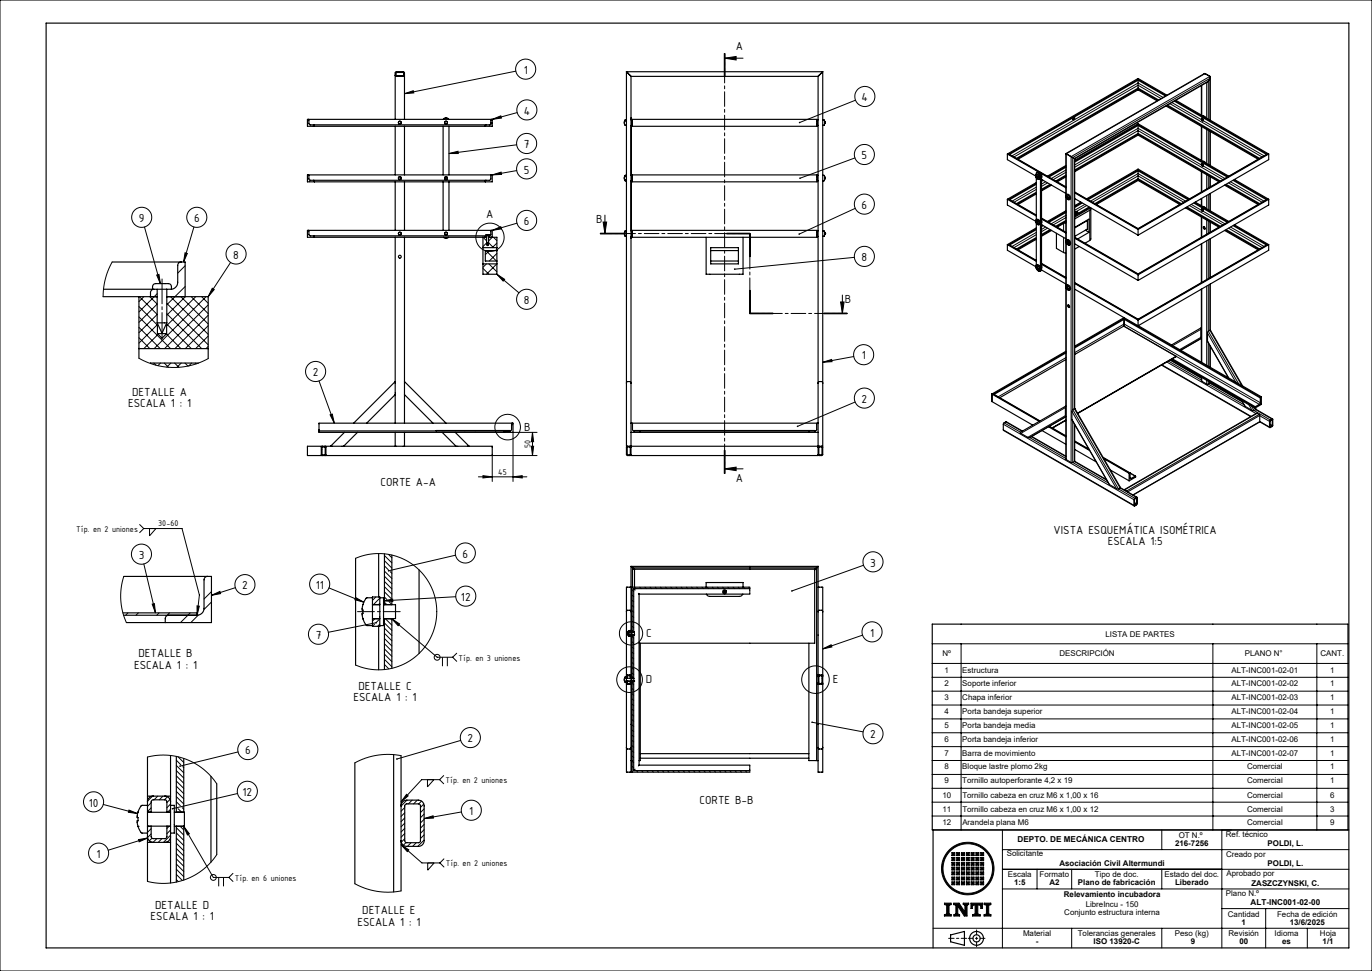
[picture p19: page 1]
CORTE A-A; CORTE B-B; DETALLE E ESCALA 1 : 1; DETALLE D ESCALA 1 : 1; DETALLE C ESCALA 1 : 1; DETALLE B; Típ. en 3 uniones ESCALA 1 : 1; DETALLE A ESCALA 1 : 1; ESCALA 1:5

30-60 Típ. en 2 uniones

VISTA ESQUEMÁTICA ISOMÉTRICA

LISTA DE PARTES

Nº | DESCRIPCIÓN | PLANO N° | CANT.
1 | Estructura | ALT-INC001-02-01 | 1
2 | Soporte inferior | ALT-INC001-02-02 | 1
3 | Chapa inferior | ALT-INC001-02-03 | 1
4 | Porta bandeja superior | ALT-INC001-02-04 | 1
5 | Porta bandeja media | ALT-INC001-02-05 | 1
6 | Porta bandeja inferior | ALT-INC001-02-06 | 1
7 | Barra de movimiento | ALT-INC001-02-07 | 1
8 | Bloque lastre plomo 2kg | Comercial | 1
9 | Tornillo autoperforante 4,2 x 19 | Comercial | 1
10 | Tornillo cabeza en cruz M6 x 1,00 x 16 | Comercial | 6
11 | Tornillo cabeza en cruz M6 x 1,00 x 12 | Comercial | 3
12 | Arandela plana M6 | Comercial | 9

Típ. en 2 uniones

DEPTO. DE MECÁNICA CENTRO | OT N.º 216-7256 | Ref. técnico POLDI, L.
Solicitante Asociación Civil Altermundi | | Creado por POLDI, L.
Escala 1:5 | Formato A2 | Tipo de doc. Plano de fabricación | Estado del doc. Liberado | Aprobado por ZASZCZYNSKI, C.

Típ. en 6 uniones

Relevamiento incubadora LibreIncu - 150 Conjunto estructura interna | | | | Plano N.º ALT-INC001-02-00

Cantidad 1 | Fecha de edición 13/6/2025

Material - | Tolerancias generales ISO 13920-C | Peso (kg) 9 | Revisión 00 | Idioma es | Hoja 1/1

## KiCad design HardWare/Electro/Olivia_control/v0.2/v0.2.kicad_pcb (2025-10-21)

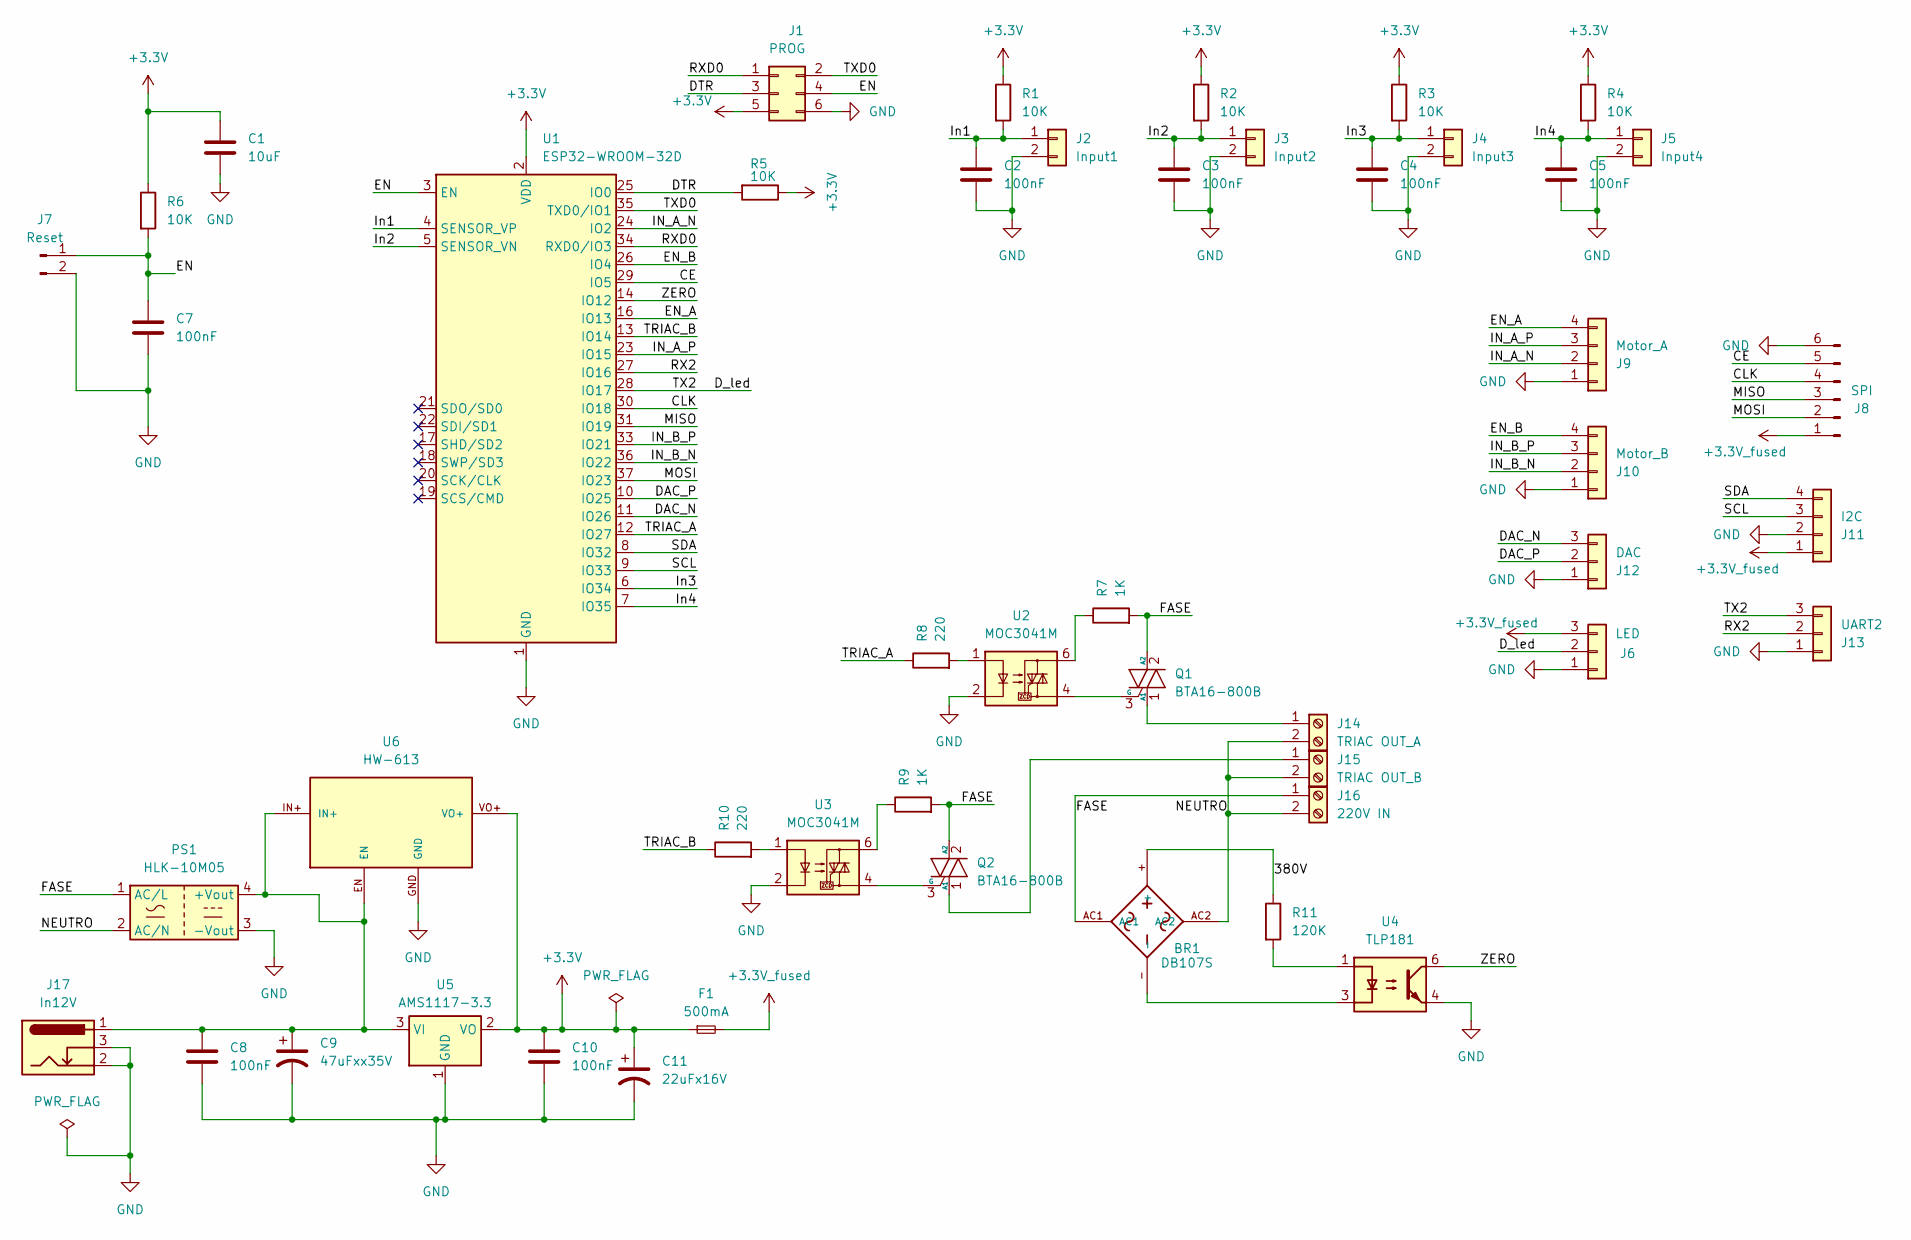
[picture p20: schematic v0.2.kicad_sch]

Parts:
BR1: DB107S; DIOB_DB107S; DigiKey_Part_Number 1655-DB107STR-ND
C1: 10uF; C_0805_2012Metric_Pad1.18x1.45mm_HandSolder
C2, C3, C4, C5, C7, C8, C10: 100nF; C_0805_2012Metric_Pad1.18x1.45mm_HandSolder
C9: 47uFxx35V; CP_EIA-6032-28_Kemet-C_Pad2.25x2.35mm_HandSolder
C11: 22uFx16V; CP_EIA-6032-28_Kemet-C_Pad2.25x2.35mm_HandSolder
F1: 500mA; Fuse_1206_3216Metric_Pad1.42x1.75mm_HandSolder
J1: PROG; PinHeader_2x03_P2.54mm_Vertical
J2: Input1; Molex_SL_171971-0002_1x02_P2.54mm_Vertical
J3: Input2; Molex_SL_171971-0002_1x02_P2.54mm_Vertical
J4: Input3; Molex_SL_171971-0002_1x02_P2.54mm_Vertical
J5: Input4; Molex_SL_171971-0002_1x02_P2.54mm_Vertical
J6: LED; Molex_SL_171971-0003_1x03_P2.54mm_Vertical
J7: Reset; PinHeader_1x02_P2.54mm_Vertical
J8: SPI; PinHeader_1x06_P2.54mm_Vertical
J9: Motor_A; Molex_SL_171971-0004_1x04_P2.54mm_Vertical
J10: Motor_B; Molex_SL_171971-0004_1x04_P2.54mm_Vertical
J11: I2C; Molex_SL_171971-0004_1x04_P2.54mm_Vertical
J12: DAC; Molex_SL_171971-0003_1x03_P2.54mm_Vertical
J13: UART2; Molex_SL_171971-0003_1x03_P2.54mm_Vertical
J14: TRIAC OUT_A; PhoenixContact_GMSTBA_2,5_2-G-7,62_1x02_P7.62mm_Horizontal
J15: TRIAC OUT_B; PhoenixContact_GMSTBA_2,5_2-G-7,62_1x02_P7.62mm_Horizontal
J16: 220V IN; PhoenixContact_GMSTBA_2,5_2-G-7,62_1x02_P7.62mm_Horizontal
J17: In12V; BarrelJack_Horizontal
PS1: HLK-10M05; Converter_ACDC_Hi-Link_HLK-10Mxx
Q1, Q2: BTA16-800B; TO-220-3_Vertical
R1, R2, R3, R4, R5, R6: 10K; R_0805_2012Metric_Pad1.20x1.40mm_HandSolder
R7, R9: 1K; R_0805_2012Metric_Pad1.20x1.40mm_HandSolder
R8, R10: 220; R_0805_2012Metric_Pad1.20x1.40mm_HandSolder
R11: 120K; R_0805_2012Metric_Pad1.20x1.40mm_HandSolder
U1: ESP32-WROOM-32D
U2, U3: MOC3041M; SMDIP-6_W9.53mm
U4: TLP181; SOIC-4_4.55x3.7mm_P2.54mm
U5: AMS1117-3.3; SOT-223-3_TabPin2
U6: HW-613

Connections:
+3.3V: C1.1, C10.1, C11.1, F1.1, J1.5, R1.1, R2.1, R3.1, R4.1, R5.1, R6.1, U1.2 (VDD), U5.2 (VO), U6.VO+
+3.3V_fused: F1.2, J6.3, J8.1, J11.1
/380V: BR1.+, R11.1
/CE: J8.5, U1.29 (IO5)
/CLK: J8.4, U1.30 (IO18)
/DAC_N: J12.3, U1.11 (IO26)
/DAC_P: J12.2, U1.10 (IO25)
/DTR: J1.3, R5.2, U1.25 (IO0)
/D_led: J6.2, J13.3, U1.28 (IO17)
/EN: C7.1, J1.4, J7.1, R6.2, U1.3 (EN)
/EN_A: J9.4, U1.16 (IO13)
/EN_B: J10.4, U1.26 (IO4)
/FASE: BR1.AC1, J16.1, PS1.1 (AC/L), Q1.2 (A2), Q2.2 (A2), R7.2, R9.2
/IN_A_N: J9.2, U1.24 (IO2)
/IN_A_P: J9.3, U1.23 (IO15)
/IN_B_N: J10.2, U1.36 (IO22)
/IN_B_P: J10.3, U1.33 (IO21)
/In1: C2.1, J2.1, R1.2, U1.4 (SENSOR_VP)
/In2: C3.1, J3.1, R2.2, U1.5 (SENSOR_VN)
/In3: C4.1, J4.1, R3.2, U1.6 (IO34)
/In4: C5.1, J5.1, R4.2, U1.7 (IO35)
/MISO: J8.3, U1.31 (IO19)
/MOSI: J8.2, U1.37 (IO23)
/NEUTRO: BR1.AC2, J14.2, J15.2, J16.2, PS1.2 (AC/N)
/RX2: J13.2, U1.27 (IO16)
/RXD0: J1.1, U1.34 (RXD0/IO3)
/SCL: J11.3, U1.9 (IO33)
/SDA: J11.4, U1.8 (IO32)
/TRIAC_A: R8.1, U1.12 (IO27)
/TRIAC_B: R10.1, U1.13 (IO14)
/TXD0: J1.2, U1.35 (TXD0/IO1)
/ZERO: U1.14 (IO12), U4.6
GND: C1.2, C2.2, C3.2, C4.2, C5.2, C7.2, C8.2, C9.2, C10.2, C11.2, J1.6, J2.2, J3.2, J4.2, J5.2, J6.1, J7.2, J8.6, J9.1, J10.1, J11.2, J12.1, J13.1, J17.2, J17.3, PS1.3 (-Vout), U1.1 (GND), U1.15 (GND), U1.38 (GND), U1.39 (GND), U2.2, U3.2, U4.4, U5.1 (GND), U6.GND
unnamed: BR1.-, U4.3
unnamed: J14.1, Q1.1 (A1)
unnamed: J15.1, Q2.1 (A1)
unnamed: C8.1, C9.1, J17.1, PS1.4 (+Vout), U5.3 (VI), U6.EN, U6.IN+
unnamed: Q1.3 (G), U2.4
unnamed: Q2.3 (G), U3.4
unnamed: R7.1, U2.6
unnamed: R8.2, U2.1
unnamed: R9.1, U3.6
unnamed: R10.2, U3.1
unnamed: R11.2, U4.1

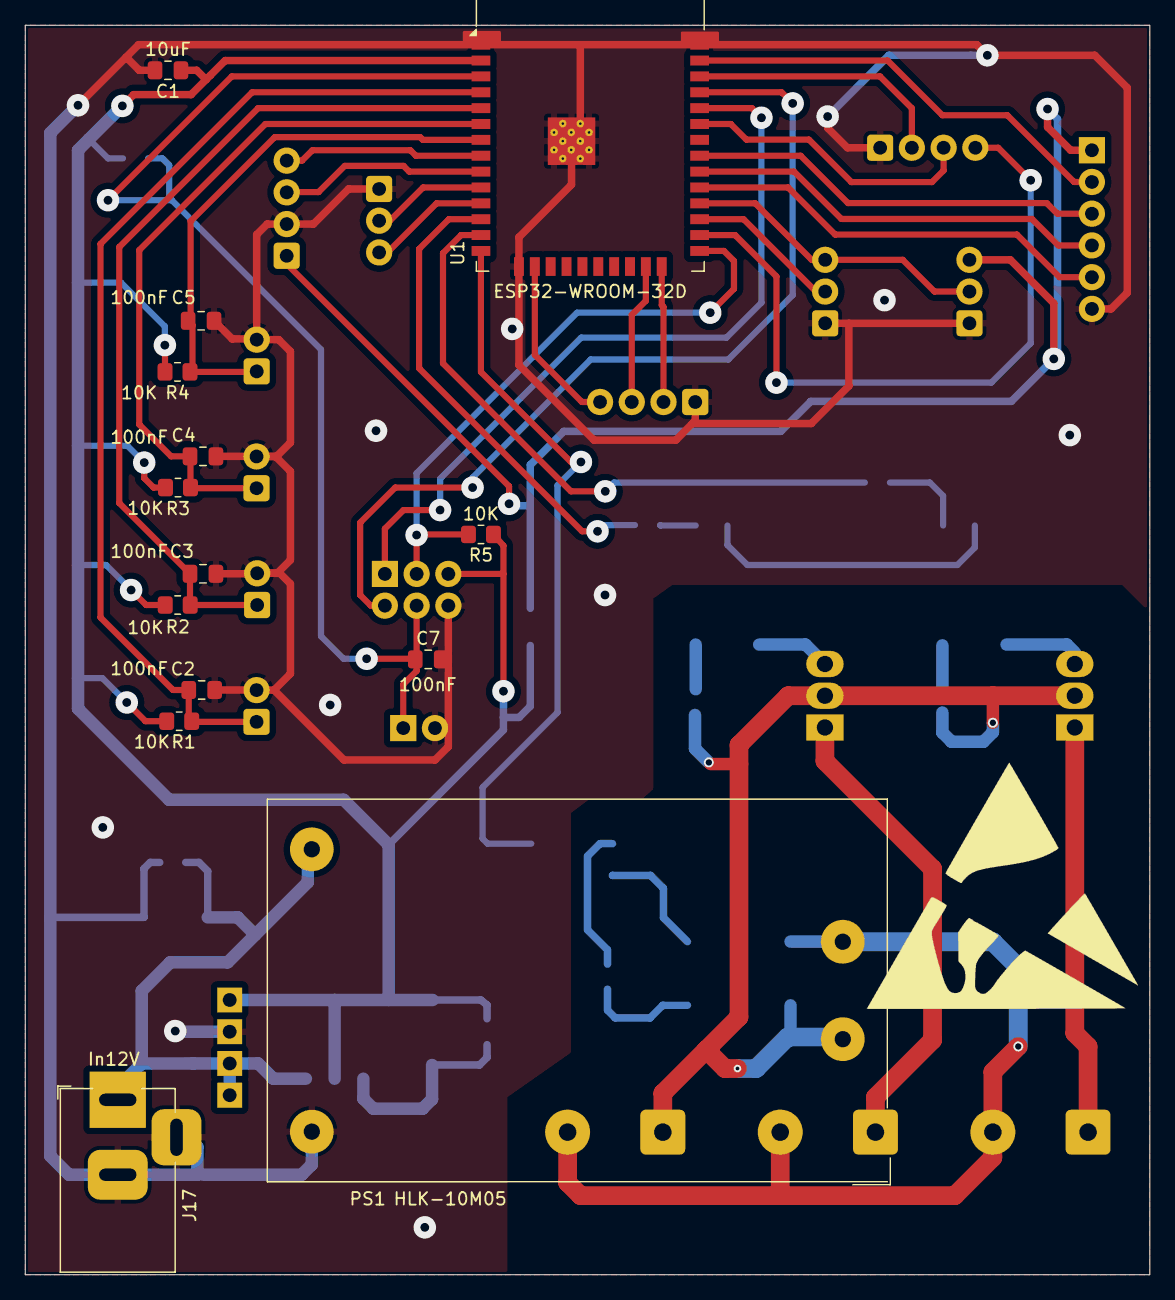
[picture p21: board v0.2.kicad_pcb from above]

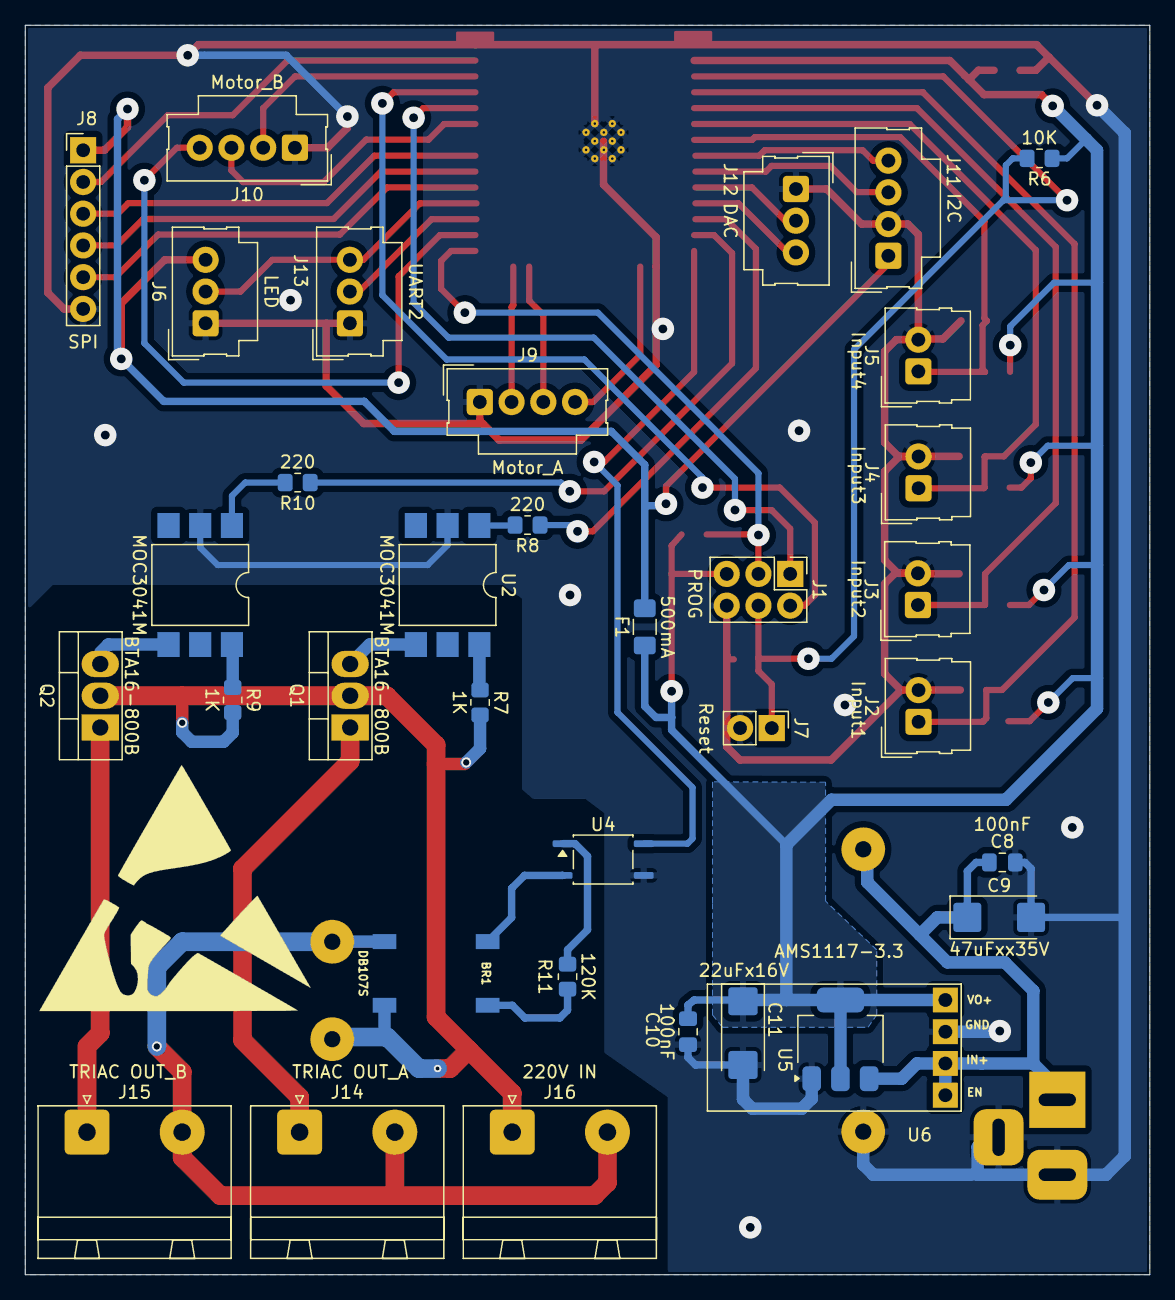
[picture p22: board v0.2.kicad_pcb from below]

Board: 2 copper layers, 90.0 x 100.0 mm, 49 parts (35 on the bottom side), 44 nets.

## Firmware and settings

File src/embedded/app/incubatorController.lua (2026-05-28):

-- SPDX-FileCopyrightText: 2025 info@altermundi.net
--
-- SPDX-License-Identifier: AGPL-3.0-only

---@diagnostic disable: lowercase-global

-----------------------------------------------------------------------------
--  This is the reference implementation to train lua fucntions. It
--  implements part of the core functionality and has some incomplete comments.
--
--  javier jorge
--
--  License:
-----------------------------------------------------------------------------
require("credentials")
require("SendToGrafana")
incubator = require("incubator")
apiserver = require("restapi")
deque = require ('deque')
log = require ('log')
configurator = require('configurator')

--log.level = "debug"
--log.usecolor=false


--holds the last 10 values
local last_temps_queue = deque.new()

controlervars = {
    rotation_enabled=true,
    rotation_activated = false,
    downtime = 0,
    uptime = 0,
    demora = 0,
    half = 0
}
-----------------------------------------------------------------------------------
-- ! @function is_temp_changing 	     verifies if temperature is changing
-- ! @param temperature						 actual temperature
------------------------------------------------------------------------------------
function is_temp_changing(temperature)
    last_temps_queue:push_right(temperature)
    if last_temps_queue:length() < 10 then
        ---les than 9 elements in the queue
        return true
    end
    if last_temps_queue:length() > 10 then
        -- remove one item
        last_temps_queue:pop_left()
    end
    local vant = nil

    for i, v in ipairs(last_temps_queue:contents()) do
        log.trace("[T] val:", i, v, vant)
        if vant ~= nil and vant ~= v then
            --everything is fine...
            return true
        end
        vant = v
    end
    --temp is not changing
    return false
end

-----------------------------------------------------------------------------------
-- ! @function temp_control 	     handles temperature control
-- ! @param temperature						 overall temperature
-- ! @param min_temp 							 temperature at which the resistor turns on
-- ! @param,max_temp 							 temperature at which the resistor turns off
------------------------------------------------------------------------------------

temp_history = {15, 15, 15}
resistor_on_counter = 0
resistor_on_temp = 0
resistor_on_derivative = 0  -- Store first derivative when heater was turned ON
low_derivative_count = 0


function temp_control(temperature, min_temp, max_temp)

    if temperature > max_temp + 4 then
        log.addError("temperature", "[T] temperature too high: " .. temperature)
    elseif temperature < min_temp - 10 then
        log.addError("temperature", "[T] temperature too low: " .. temperature)   
    end

    -- Smooth temperature
    temp_history[1] = temp_history[2]
    temp_history[2] = temp_history[3]
    temp_history[3] = temperature

    smooth_temp = ( temp_history[1]+ temp_history[2]+ temp_history[3]) / 3

    log.trace("[T] temp " .. temperature .. " min:" .. min_temp .. " max:" .. max_temp ..
              " count " .. resistor_on_counter .. " resistor on temp " .. resistor_on_temp..
                " smooth temp " .. smooth_temp)

    if resistor_on_counter == 13 then
        resistor_on_temp = smooth_temp  -- Store temperature after heater was turned ON
    end

    -- Check if the temperature is increasing effectively
    local tolerance = 0.5
    if resistor_on_counter == 200 then ---aprox 10 min
        if resistor_on_temp +tolerance  <  smooth_temp then
            log.trace("[T] temperature is increasing properly !!!!!")
            low_derivative_count = 0  -- Reset the counter if temperature is increasing
        else
            log.warn("[T] temperature too low: " .. smooth_temp)
            log.warn("[T] temperature is not increasing enough.. derivative: " ..
            resistor_on_temp +tolerance.."  <  "..smooth_temp )

            if temperature < min_temp - 4 then
                log.addError("temperature", "[T] temperature too low: " .. temperature)
            end
            log.addError("temperature", "[T] temperature is not increasing enough..: " ..
            resistor_on_temp +tolerance.."  <  "..smooth_temp )
            
        end
        resistor_on_counter = 14 --if resistor is "on" it wont be 0 next time ref temp is kept.
    end



    if incubator.resistor then
        resistor_on_counter=resistor_on_counter+1
    else
        resistor_on_counter=0
    end

    if temperature <= min_temp then
        if is_temp_changing(temperature) then
            log.trace("[T] temperature is changing")
            log.trace("[T] turn resistor on")
            incubator.heater(true)
        else
            log.addError("temperature","[T] temperature is not changing")
            log.trace("[T] turn resistor off")
            incubator.heater(false)
        end
    elseif temperature >= max_temp then
        incubator.heater(false)
        log.trace("[T] turn resistor off")
    end -- end if
end     -- end function


    function get_days_since_start(start_date_ms)
        if start_date_ms == 0 then return 0 end
        
        -- Current time in milliseconds
        local current_time_ms = time.get() * 1000  -- Convert seconds to milliseconds
        
        -- Calculate elapsed time in days
        local ms_per_day = 24 * 60 * 60 * 1000
        local days_passed = math.floor((current_time_ms - start_date_ms) / ms_per_day)
        
        return days_passed
    end
    
    function should_increase_humidity()
        local tray_one_days = get_days_since_start(incubator.tray_one_date)
        local tray_two_days = get_days_since_start(incubator.tray_two_date)
        local tray_three_days = get_days_since_start(incubator.tray_three_date)
        
        -- Check if any tray is between day 18 and 21
        local function is_in_high_humidity_period(days)
            return days >= incubator.incubation_period and days <= 21
        end
        
        log.trace(string.format("Days since start - Tray1: %d, Tray2: %d, Tray3: %d", 
            tray_one_days, tray_two_days, tray_three_days))
            
        return is_in_high_humidity_period(tray_one_days) or
               is_in_high_humidity_period(tray_two_days) or
               is_in_high_humidity_period(tray_three_days)
    end
    
    function get_adjusted_humidity_limits(base_min_hum, base_max_hum)
        if should_increase_humidity() then
            return base_min_hum + 10, base_max_hum + 10
        end
        return base_min_hum, base_max_hum
    end
    
        

hum_off_counter=0
hum_on_hum=0
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

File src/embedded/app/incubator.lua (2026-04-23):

-- Copyright (C) 2023  Asociación Civil Altermundi <info@altermundi.net>
-- Copyright (c) 2023  Instituto Nacional de Tecnología Industrial
-- Copyright (c) 2023  Javier Jorge <jjorge@inti.gob.ar>
-- SPDX-FileCopyrightText: 2025 info@altermundi.net
--
-- SPDX-License-Identifier: AGPL-3.0-only

-----------------------------------------------------------------------------
credentials = require('credentials')

local M = {
	name                            = ..., -- module name, upvalue from require('module-name')
	model                           = nil, -- M model:
	resistor                        = false,
	humidifier                      = false,
	rotation                        = false,
	temperature                     = 99.9, -- integer value of temperature [0.01 C]
	pressure                        = 0, -- integer value of preassure [Pa]=[0.01 hPa]
	humidity                        = 0, -- integer value of rel.humidity [0.01 %]
	is_testing                      = false,
	max_temp                        = 37.7,
	min_temp                        = 37.5,
	is_sensorok                     = false,
	is_simulate_temp_local          = false,
	rotation_switch_deactivate_time = 10000, -- max amount of time the sensor is down when the incubator is moving in ms
	rotation_duration               = 50000, -- max amount of time the rotation should last in ms
	rotation_period                 = 3600000, -- time in ms
	-- NodeMCU timer maximum limit: 6,844,835 ms (~1.9 hours)
	-- Use safe maximum of 6,000,000 ms (~1.67 hours) to account for variations
	MAX_TIMER_PERIOD                = 6000000, -- NodeMCU safe timer limit
	humidifier_enabled              = true,
	max_hum                         = 100,
	min_hum                         = 1,
	humidifier_min_temp             = 35.0, -- minimum temperature to enable humidifier
	humidifier_max_on_time          = 400, -- ms !!
	humidifier_off_time             = 120, -- sec !!
	hum_turn_on_time                = 0,
	hum_turn_off_time               = 0,
	humidifier_timer                = nil,  -- tmr object for max-on-time enforcement
	tray_one_date = 0,
	tray_two_date = 0,
	tray_three_date = 0,
	incubation_period = 18,
	hash = 1235,
	incubator_name = string.format("incu-%s",wifi.sta.getmac()),
	rotate_up                       = true,
	rotation_enabled				= true,
    rotation_activated 				= false
}

_G[M.name] = M

local sensor = require('bme280')

function M.startbme()
	if sensor.init(GPIOBMESDA, GPIOBMESCL, true) then
		M.is_sensorok = true
	else
		M.is_sensorok = false
	end
end

function M.init_values()
	M.startbme()
	gpio.config({ gpio = { GPIORESISTOR, GPIOVOLTEO_UP, GPIOVOLTEO_DOWN, GPIOHUMID, GPIOVOLTEO_EN }, dir = gpio.OUT })
	-- config inputs
	gpio.config({ gpio = { GPIOREEDS_DOWN, GPIOREEDS_UP }, dir = gpio.IN, pull = gpio.PULL_UP })

	gpio.set_drive(GPIOVOLTEO_UP, gpio.DRIVE_3)
	gpio.set_drive(GPIOVOLTEO_DOWN, gpio.DRIVE_3)
	gpio.set_drive(GPIOHUMID, gpio.DRIVE_3)
	gpio.set_drive(GPIORESISTOR, gpio.DRIVE_3)
	gpio.set_drive(GPIOVOLTEO_EN, gpio.DRIVE_3)



	gpio.write(GPIOVOLTEO_UP, 0)
	gpio.write(GPIOVOLTEO_DOWN, 0)
	gpio.write(GPIOHUMID, 1)
	gpio.write(GPIORESISTOR, 0)
	gpio.write(GPIOVOLTEO_EN, 0)
end -- end function

-------------------------------------
-- @function enable_testing 	Enables testing mode asserting correct M funcioning
--
-- @param min 								is equal to the minimum temperature to test
-- @param max 								is equal to the maximum temperature to test
-------------------------------------
function M.enable_testing(simulatetemp)
	M.is_testing = true;
	M.is_simulate_temp_local = simulatetemp
end --end function

-------------------------------------
-- simulates a change in sensors acording to actuators and returns sensor readings
--
-- @returns temperature, humidity, pressure
-------------------------------------
function M.get_values()
	if M.is_simulate_temp_local then
		if M.resistor then
			M.temperature = (M.temperature + 1)
		else
			M.temperature = (M.temperature - math.random(1, 15))
		end --end if

		if M.humidifier then
			M.humidity = (M.humidity + 1)
		else
			M.humidity = (M.humidity - math.random(1, 4))
		end --end if
	else
		M.startbme()
		if M.is_sensorok then
			sensor.read()
			if (sensor.temperature / 100) < -40 or (sensor.temperature / 100) > 86 then
				M.temperature = 99.9
				M.humidity = 99.9
				M.pressure = 99.9
				log.addError("temperature","temperature is out of range T:"..sensor.temperature / 100 )
				--try to restart bme
			else
				M.temperature = (sensor.temperature / 100)
				M.humidity = (sensor.humidity / 100)
				M.pressure = (sensor.pressure / 100)
			end
		else
			M.temperature = 99.9
			M.humidity = 99.9
			M.pressure = 99.9
			log.addError("sensors","Failed to start bme, Please check the cables and connections.")
		end -- end if
	end --if end

	return M.temperature, M.humidity, M.pressure
end --end function

-------------------------------------
-- @function heater 					Activates or deactivates heater
--
-- @param status "true" 			increments temperature, "false" temp "decrements"
-------------------------------------
function M.heater(status --[[bool]])
	M.resistor = status
	if status then
		gpio.write(GPIORESISTOR, 1)
	else
		gpio.write(GPIORESISTOR, 0)
	end
	M.assert_conditions()
end --end function

function M.assert_conditions()
	log.trace("temp actual ", M.temperature, ", max ", M.max_temp, ",min ", M.min_temp, ",resitor status ", M.resistor)
	if M.is_testing then
		if (M.temperature > M.max_temp and M.resistor) then
			log.addError("temperature","temperature > max_temp and resistor is on")
			--assert(not M.resistor)
		end --if end
		if (M.temperature < M.min_temp and not M.resistor) then
			log.addError("temperature","temperature < M.min_temp and resistor is off")
			--assert(M.resistor)
		end --if end
	end -- if is_testing
end   --end fucition

function M.get_uptime_in_sec()
	local high_bytes, _ = node.uptime()
	return tonumber((high_bytes / 1000000))
end
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

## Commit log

2024-12-21 add reboot timer to avoid tansmision stop
    [incubatorController.lua]
2024-12-21 fix timer call
2024-12-22 fix reboot time to one hour
    [incubatorController.lua]
2025-03-19 ordeno y elimino archivos HardWare
    [CableCanalSoporteReedSwitch.STEP, CableCanalSoporteReedSwitch.STL, CarcasaPolea_conColumnas.stl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]
2025-05-06 Update TESTING.md
    add other pin initialization
2025-06-06 Reemplazo de Conector 220V por borneras 7,62mm.
    [v0.2.kicad_pcb, v0.2.kicad_sch]
2025-06-07 Cambio de medidas de huecos y pads para llevar a proceso de fabricación industrial. La version original tiene margenes de tolerancia adaptados a las impresiciones de la fabricación manual.
    [v0.2.kicad_pcb]
2025-06-07 Cambio de despeje de zonas para llevar a proceso de fabricación industrial. La version original tiene margenes de tolerancia adaptados a las impresiciones de la fabricación manual.
    [v0.2.kicad_pcb]
2025-06-07 Añadida serigrafía para fabricación industrial.
    [v0.2.kicad_pcb]
2025-06-08 Pequenos fixes en sector 220V. Imagenes de vista, Gerbers y pdf de esquematico generados. Limpieza.
    [v0.2.kicad_pcb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]
2025-06-12 Added soldering mask to gerber outputs.
    [v0-B_Silkscreen.gbr, v0.2-B_Cu.gbr, v0.2-B_Mask.gbr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]
2025-07-02 added structural plans
    [ALT-INC001-05-01.STL, ALT-INC001-05-02.STL, ALT-INC001-12-03.STL]
2025-08-03 Add BOM file with updated component configuration
    - Added bill-of-materials.csv for v0.2 hardware
    - Updated KiCad project settings for BOM export
    - Excluded test points from BOM output
    [bill-of-materials.csv, v0.2.kicad_sch]
2025-08-12 Fix: Start essential services independently of rotation system
    - Move temp_control_timer and send_data_timer initialization to always execute
    - Prevent incubator from being completely disabled if rotation fails
    - Temperature/humidity control and data sending now work even with rotation errors
    - Improves system reliability and fault tolerance
    [incubatorController.lua]
2025-08-12 Add missing low humidity alerts
    - Generate log.addError() when humidity drops below minimum threshold
    - Previously only logged trace messages for low humidity conditions
    - Now alerts are properly sent for humidity too low scenarios
    - Improves monitoring completeness for humidity control system
    Fixes #205
    [incubatorController.lua]
2025-08-12 Fix: Add timer period validation to prevent system crashes
    - Add MAX_TIMER_PERIOD constant (6,000,000 ms) based on NodeMCU limits
    - Validate rotation_period range: 60,000ms - 6,000,000ms (1min - 1.67hrs)
    - Prevent timer registration failures that cause reset loops
    - Add proper error logging for invalid period values
    - Ensure system stability when large periods are configured via API
    Fixes #201
    [incubator.lua]
2025-08-12 Add configurable minimum temperature for humidifier activation
    - Add humidifier_min_temp variable (default 38.0°C) in incubator module
    - Implement set_humidifier_min_temp() function with validation (30-45°C range)
    - Add API configuration support via configurator module
    - Block humidifier activation when temperature < minimum threshold
    - Enhance humidity alerts to show temperature blocking information
    - Prevents premature humidification before incubator reaches thermal regime
    Fixes #93
    [incubator.lua, incubatorController.lua]
2025-08-14 Update TESTING.md
    improve sensor testing
2025-08-14 fix rotation test; lua is single process and the previous timings could not be met
    [incubatorController.lua]
2025-08-20 add throttle and memory check
2025-08-20 throttle by message with random interval
2025-10-21 replaced 4N25 with TLP181
    [v0.2.kicad_pcb, v0.2.kicad_sch]
2026-03-10 improve logging and fix time comparison
    [incubator.lua]
2026-04-09 fix error400 in send to grafana
    [SendToGrafana.lua]
2026-05-28 add names and fix 12v lines
2026-05-28 agregar documentación
    [libreincu_BOM.csv]
2026-11-13 Manual v3 (#215)
    * PDF del manual v3 regenerado
    * Exportador y capturas: los reed van con el carro y los finales de carrera
    * CAD v3 regenerado: KFL08 de catálogo, muñones, perno del carro en planchuela y reed
    Fuente congelada, STEP, capturas y animación.
    * Desarrollos acotados regenerados con los DXF y el script actuales
    * Montaje: muñones de las cunas, perno del carro en planchuela y posición de los reed
    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
2026-11-13 Revierte "Manual v3 (#215)"
    Se mergeó por error en este repositorio; el manual v3 vive en Pablomonte/LibreIncu-150.
